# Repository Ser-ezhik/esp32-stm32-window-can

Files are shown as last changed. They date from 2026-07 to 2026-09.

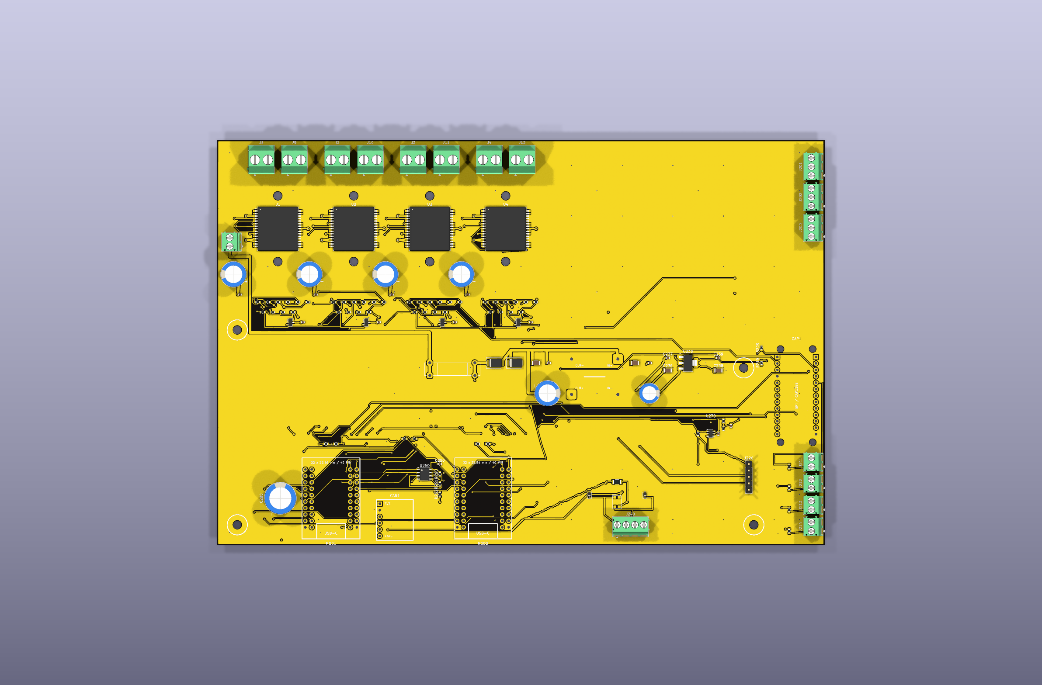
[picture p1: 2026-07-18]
hardware/WINDOW-4CH/WINDOW-4CH-top.png

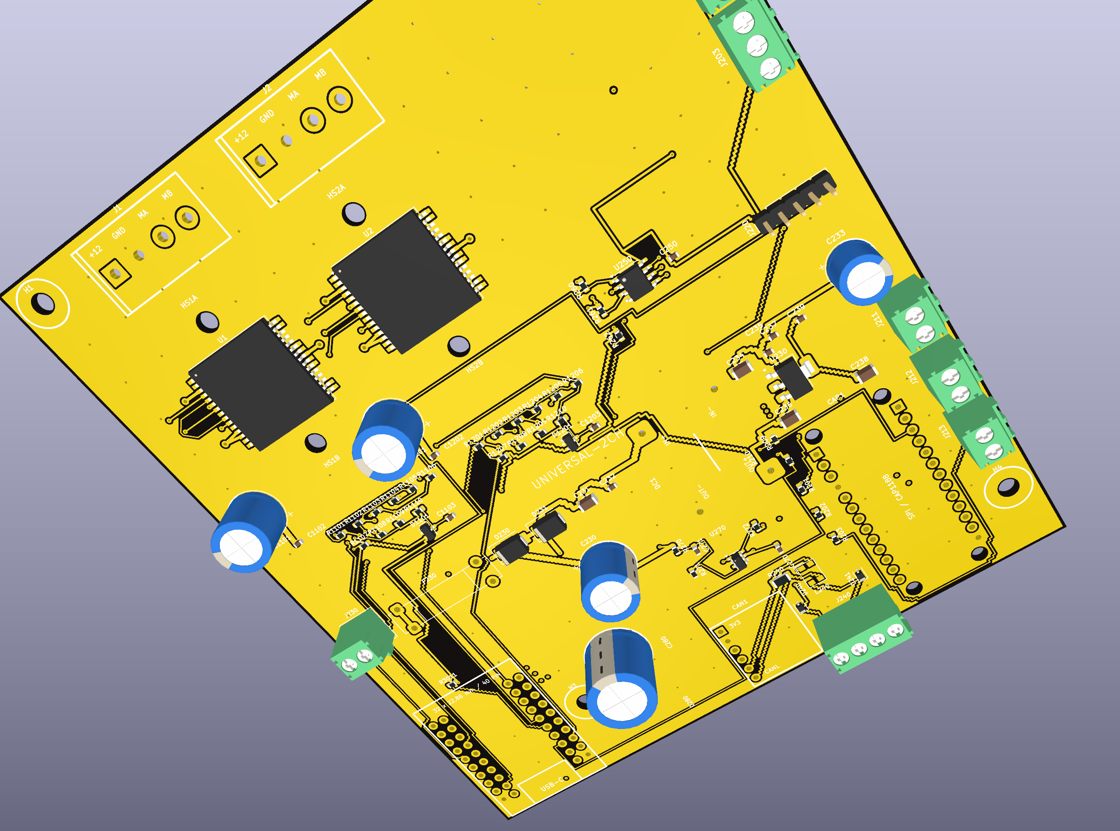
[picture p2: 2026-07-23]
hardware/UNIVERSAL-2CH/kicad/UNIVERSAL-2CH-render-iso-2400.png

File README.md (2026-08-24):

# ESP32 + STM32 window and door controller

New hardware generation of the original `esp32-rp2040-window-rs485` project.
The legacy source and all historic firmware releases remain in Git history and
under the `legacy-rp2040-import` tag. New releases never replace previous binaries.

## Target architecture

- ESP32-S3: CC1101 433 MHz radio, Wi-Fi, web UI, configuration backup and CAN coordinator.
- One cabinet per physical window or door.
- One universal STM32F103C8T6 master in each cabinet: two VNH5019A-E channels, CAN,
  CAP1188 over 4-wire SPI, three D-M9 position sensors and up to three local UART slaves.
- Up to three identical STM32 boards as local slaves, two VNH5019A-E channels per board.
- One firmware image for every STM32 board. `SLOT_ID` pins on the cabinet carrier select
  master/slave role, so a pre-flashed spare module can replace any controller.
- Cabinet identity is stored in a 25LCxx SPI EEPROM on the non-removable carrier board.

## Current development status

The current releases are STM32 two-channel `0.1.0-alpha.14`, STM32 four-channel
`0.1.0-alpha.13`, and ESP32-S3 `0.1.0-alpha.12`:

- hardware bxCAN at 500 kbit/s;
- three hardware UART links at 250 kbit/s with CRC16 frames;
- VNH5019A-E PWM, direction, current sense and diagnostic monitoring;
- CAP1188 4-wire SPI driver, no I2C;
- three active-low D-M9N inputs;
- current disappearance end-stop detection;
- overcurrent, no-current, timeout, edge and communication fail-safe states;
- per-direction full-stroke calibration data and PWM equalization;
- carrier provisioning/discovery protocol;
- watchdog and safe outputs at boot.
- bounded CAN/UART receive work per control-loop pass;
- validation of command, fault and object-type values received from the bus;
- verified internal configuration writes with retries and a latched storage fault;
- ESP32-S3 CAN coordinator with CC1101 receiver and configuration stored in NVS;
- object-based web UI for up to 64 windows/doors, actuator telemetry, events and emergency stop;
- editable 433 MHz button assignments;
- separate open/close calibration, position-aware full-cycle calibration and calibration reset;
- per-input D-M9N/D-M9P polarity stored in the cabinet carrier EEPROM.

The `alpha.1` STM32 binaries and tag remain unchanged. `alpha.2` is a new release
because the CAN protocol gained a calibration-reset command.

ESP32 `alpha.3` fixes mobile-width overflow found during Chrome testing. The
wide actuator table now scrolls inside its own container without widening the page.

ESP32 `alpha.4` targets the tested ESP32-S3 N16R8 module: 16 MB quad Flash,
PSRAM disabled (the firmware does not need it), and a 3 MB application partition. It also prints startup diagnostics
at 115200 baud. This hardware is verified with Arduino-ESP32 core `3.0.7`;
do not use core `3.3.8` for it because Wi-Fi startup is unstable on the tested board.
Generic 4 MB images remain archived under their original tags.

## Build STM32 firmware

Install Arduino CLI and the official STM32 core, then run:

```powershell
arduino-cli compile `
  --fqbn "STMicroelectronics:stm32:GenF1:pnum=GENERIC_F103C8TX,xserial=none,usb=none,opt=oslto,dbg=none,rtlib=nano" `
  --libraries libraries `
  --export-binaries `
  ArduinoIDE\STM32_Universal_Actuator_Node
```

The project deliberately targets the real 64 KiB capacity of STM32F103C8T6 and
does not rely on unofficial 128 KiB clone behaviour.

## Build ESP32-S3 firmware

```powershell
powershell -ExecutionPolicy Bypass -File tools\embed-web.ps1
arduino-cli core install esp32:esp32@3.0.7
arduino-cli compile `
  --fqbn "esp32:esp32:esp32s3:FlashMode=dio,FlashSize=16M,PartitionScheme=app3M_fat9M_16MB,PSRAM=disabled" `
  --libraries libraries `
  --export-binaries ArduinoIDE\ESP32_CC1101_CAN_Master
```

The current web interface intentionally exposes only full open, full close and
stop. A partial ventilation command will be added only after its position rule
or dedicated sensor is defined and bench-tested.

## Documentation

- `docs/HARDWARE_ARCHITECTURE.md`
- `docs/CAN_PROTOCOL.md`
- `docs/SAFETY_AND_RECOVERY.md`
- `docs/BOM_v0.1.md`
- `hardware/DOOR-8CH/README.md`
- `hardware/WINDOW-4CH/README.md`

This is safety-related motion-control software. Test with disconnected mechanics
and current-limited power before connecting a door or window.

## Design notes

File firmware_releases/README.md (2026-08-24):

# Архив версий прошивок

В этой папке сохраняются готовые версии прошивок ESP32 и RP2040.

Правило работы:

- рабочие `.ino` в `ArduinoIDE/` можно редактировать;
- готовые проверенные версии копируются сюда в отдельную папку;
- имена папок содержат дату, номер версии и краткое описание;
- старые папки релизов не затираются, чтобы можно было вернуться назад.

## Текущие версии

- `2026-08-25_v0.1.0-alpha.14-stm32-validated-io` - двухканальная STM32 с
  ограничением обработки очередей CAN/UART, проверкой входящих значений и
  проверяемой записью настроек EEPROM.
- `2026-08-25_v0.1.0-alpha.12-esp32-config-storage-fault` - ESP32-S3 с
  отображением ошибки памяти настроек STM32.

- `2026-07-08_v1.1_safety-fixes` - версия с исправлениями надежности RF, backup, watchdog, INA219, CAP1188 и I2C.
- `2026-07-08_v1.2_reed-stop` - RP2040 версия, где целевые герконы `Открыто`, `Проветривание`, `Закрыто` останавливают актуаторы.
- `2026-07-08_v1.2_reed-labels` - ESP32 версия, где герконы в веб-интерфейсе отображаются с названиями и статусом `0/1`.
- `2026-07-08_v1.3_watchdog-counter` - ESP32 и RP2040 версия со счетчиком watchdog-перезапусков RP2040.
- `2026-07-08_v1.4_web-update` - ESP32 версия с web-обновлением прошивки ESP32 через файл `.bin`.

## Как выбирать файл

- Для ESP32 через веб-обновление обычно используется `.bin`.
- Для полной прошивки ESP32 используется `.merged.bin`.
- Для RP2040 используется `.uf2`.

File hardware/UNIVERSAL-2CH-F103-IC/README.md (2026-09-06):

# UNIVERSAL-2CH-F103-IC

Compact universal two-actuator controller board with direct-mounted
STM32F103C8T6 and CAP1188 ICs.

## Board status

- two copper layers: F.Cu and B.Cu;
- board size: 83.1 x 100.1 mm;
- 106 footprints;
- 2 VNH5019A-E actuator channels;
- 2 protected 5 V reed-sensor connectors (5V/SIG/GND);
- 3 capacitive sensor connectors;
- CAN transceiver module socket;
- external fixed 5 V DC-DC footprint: 18 x 13 mm body, 15 x 9 mm pad spacing;
- SPI EEPROM and power-fail supervision;
- full GND planes on both layers;
- local copper reinforcement on all motor output and fused 12 V routes.

## Verification

KiCad 10 DRC result:

- 0 DRC errors, 0 warnings;
- 0 unconnected pads;
- 0 footprint errors.

These results were regenerated on 2026-09-06 after relocating conflicting
silkscreen text and refilling copper with a 0.8 mm minimum feature width.
Check severities were not weakened. See fabrication/v1.7-alpha15-drc-clean/RELEASE.md.

Open `kicad/UNIVERSAL-2CH-F103-IC.kicad_pro` in KiCad.

## Assembly links

The board requires three insulated wire links: `C280+ -> J280B`,
`TP290 -> JP290 (J220.6)`, and `D230.1 -> C270.1`.
See `REED_5V_PROTECTION.md` before powering the
board.

## Fabrication releases

- `fabrication/v1.7-alpha15-drc-clean` contains current Gerbers, drill files,
  stencil files, BOM and CPL. C340 is on the top side. Prior releases are stale
  for this PCB revision and must not be mixed with these manufacturing files.
- `fabrication/v1.6-reed5v-protected` is a historical release. It
  powers J201/J202 from 5 V and adds 4.7 kOhm protected signal inputs.
- `fabrication/v1.5-c88056` is retained as the preceding release. It preserves the
  verified v1.4 Gerber/CPL and replaces the unavailable L240 with TDK
  ACT45B-101-2P-TL003 (`C88056`).
- `fabrication/v1.4-orientation-verified` is retained as the preceding release.
  It includes `F.Mask` and `B.Mask`, the corrected JLCPCB BOM/CPL files, DRC
  report, Gerber ZIP, the JLCPCB placement screenshot, and a component-by-
  component orientation check. The JLCPCB cart project is `Y14`.
- `fabrication/v1.1-maskfix`, `v1.2-orientationfix`, and
  `v1.3-orientation-audit` are retained for history and must not be ordered.
- `fabrication/v1.0-audited` must not be manufactured: its Gerber archive was
  generated without the solder-mask layers.

The release build stops with an error if either copper layer, either
solder-mask layer, or the board outline is missing.

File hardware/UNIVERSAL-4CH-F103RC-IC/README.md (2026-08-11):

# UNIVERSAL-4CH-F103RC-IC

Compact four-actuator controller based on one STM32F103RCT6.

## Routed board

- Board outline: 124.05 x 93.05 mm.
- Layers: two copper layers.
- Controller: STM32F103RCT6, LQFP64, soldered on the bottom.
- Motor drivers: four VNH5019A-E, soldered on the bottom.
- Motor connectors: four keyed 4-pin connectors on the top edge.
- Reed switches: three 3-pin connectors on the bottom edge.
- Capacitive sensors: three 2-pin connectors on the right edge.
- CAP1188, SPI flash EEPROM and low-voltage SMD parts are soldered on the bottom.
- CAN transceiver and MP1584 5 V converter remain replaceable top-side modules.
- Two unplated heatsink mounting holes are provided around each VNH5019A-E.
- The 12 main motor supply/output paths are reinforced by boolean-union copper
  zones with a nominal 3.0 mm width; local connector/pad breakouts narrow only
  where adjacent plated contacts limit the available clearance.
- Every clearance-permitted underlying power segment is widened to 0.6 mm;
  only short package/connector fanouts retain their smaller library width and
  remain fully covered by the reinforced copper zones.
- CH1 OUTA has a nine-via transition bank and CH2 OUTA has six parallel vias.
  CH3/CH4 OUTA use 3 x 3 via banks at both transitions, and the CH4 OUTB
  auxiliary transition has four parallel vias. CH1-CH3 OUTB stay on B.Cu
  throughout and therefore carry no motor current through vias.
- Both copper layers include GND planes.
- Reed connectors supply 5 V and use 4.7 kohm series protection for accidental
  D-M9P connection to a 3.3 V MCU input.

## Assembly note

Fit one short insulated wire from the positive lead of `C280` to `J280B` on the
bottom side. This connects the hold-up capacitor after `D280` to the input of
the 3.3 V regulator. The connection is explicitly marked on B.Silkscreen.

## Checks

- KiCad DRC: 0 violations, 0 unconnected pads.
- Automated critical pad/net contract check: PASS.
- Automated effective-copper audit: PASS for all 12 power paths. With 2 oz
  copper, estimated planar path resistance is 1.1-2.6 milliohm and estimated
  dissipation at the 5 A design-check current is at most 0.10 W per path
  (excluding the small additional resistance of plated transitions).
- Four VNH channels, CAP1188 SPI, EEPROM SPI, remapped CAN, SWD, power-good and
  three protected reed inputs are included in the contract check.
- Channel 3 and 4 ADC clamps and diagnostic pull-ups are connected to the
  powered `S1_3V3` rail; the electrical audit rejects the former orphan rail.

Use 2 oz finished copper for production. The expected actuator current is
about 2.5 A; 5 A is the routing verification current, not the continuous-load
rating of the complete controller assembly.

## Firmware

Use `ArduinoIDE/STM32_Universal_Actuator_Node_4CH_F103RC`. It publishes two
classic-CAN actuator frames, each containing two local channels, and is
compatible with the existing ESP32 four-actuator object model. Build it with
`tools/build-stm32-4ch-f103rc.ps1`. The existing F103C8 two-channel binary must
not be flashed onto this board.

Open `kicad/UNIVERSAL-4CH-F103RC-IC.kicad_pcb` in KiCad 10.

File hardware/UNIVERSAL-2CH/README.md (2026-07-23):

# UNIVERSAL-2CH

Compact universal carrier for two 12 V linear actuators. The same assembled
board can be provisioned as an optional sliding-door drive or as a two-actuator
vent/window node.

## Hardware

- Board: 106 x 112 mm, four copper layers.
- Controller: one socketed STM32F103C8T6 Mini.
- Drivers: two VNH5019A-E channels with mounting holes for top heatsinks.
- Network: socketed SN65HVD230 CAN transceiver module and protected edge entry.
- Touch safety: optional socketed CAP1188 SPI module with three field inputs.
- Position: three protected reed-switch inputs.
- Identity and journal: 25LC256 carrier EEPROM.
- Supply: socketed MP1584 12 V to 5 V converter, 3.3 V regulator, power-good
  monitor, and logic hold-up capacitor.

## Connectors

- `J1`, `J2`: actuator connectors, `+12V / GND / MA / MB`.
- `J201` to `J203`: open, closed, and in-place reed sensors.
- `J211` to `J213`: capacitive field sensors.
- `J230`: protected 12 V logic input.
- `J240`: `CANH / CANL / GND / shield`.
- `J220`: SWD service header.

All external field connectors are placed on board edges. Power routing and
VNH5019 devices occupy the upper half; CAN and touch electronics are kept away
from the motor outputs.

The field interfaces use board-mounted male headers with removable female cable
plugs. Connector fronts face outwards; the layout includes body clearance
between adjacent plugs and keeps the cable-entry space outside the board edge.

## KiCad Files

- `kicad/UNIVERSAL-2CH.kicad_pcb`: routed PCB.
- `kicad/UNIVERSAL-2CH.kicad_sch`: complete flat schematic.
- `kicad/UNIVERSAL-2CH-multisheet.kicad_sch`: multisheet root schematic.
- `kicad/UNIVERSAL-2CH-routed-top.png`: final top-side 3D render.
- `kicad/UNIVERSAL-2CH-routed-iso.png`: final isometric 3D render.
- `UNIVERSAL-2CH-BOM.csv`: grouped BOM.

## Verification

- PCB DRC: 0 violations, 0 unconnected items.
- Flat schematic ERC: 0 errors, 0 warnings.
- Multisheet schematic ERC: 0 errors, 0 warnings.
- PCB-to-schematic sync: 90 references, 283 connected pads, 38 explicit NCs.
- Routing geometry: straight segments with 45-degree transitions; no staircase
  routing on long connections.
- STM32 pin audit: 27 functional socket connections match `config.h`.
- STM32 build: 24,136 bytes Flash (36%), 3,500 bytes RAM (17%).

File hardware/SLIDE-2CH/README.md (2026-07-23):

# SLIDE-2CH optional automatic-door module

## Purpose

`SLIDE-2CH` is an optional compact CAN node for two 12 V actuators that slide
door leaves after the main door mechanism has opened. It uses the same socketed
STM32 module, VNH5019A-E circuit and universal firmware as the existing boards.
No different STM32 binary is required.

The module is configured as:

- object type `Window`;
- actuator count `2`;
- slave count `0`;
- CAP1188 enabled mask `0`;
- its own unique CAN cabinet number.

ESP32 links this node to a single- or double-door object. When the option is
disabled or the module is absent, the existing door operates unchanged.

## Required hardware

- one socketed STM32F103C8T6 mini module;
- two VNH5019A-E bridges with the complete DOOR-8CH passive and current-sense
  networks;
- one SN65HVD230 CAN transceiver module;
- one 25LC256 carrier EEPROM;
- one MP1584 12 V to 5 V module and the existing protected logic-power input;
- two keyed four-pin actuator connectors carrying 12 V, GND, OUTA and OUTB;
- one CAN connector with TVS, common-mode choke and optional DNP 120 Ohm
  termination;
- three D-M9 reed inputs: fully open, fully closed and mechanism in-place;
- per-channel 7.5 A fuses and local 470 uF / 35 V capacitors;
- SWD connector, power-good circuit and MASTER hold-up supply.

The open and closed reeds are mandatory for deterministic operation after a
cold start. The actuator internal limit switches remain the normal end-of-travel
and calibration signal, but they cannot report the initial position while the
motor is unpowered.

## Safe sequence

Opening:

1. ESP32 verifies that both CAN nodes are online and fault-free.
2. The main door mechanism opens completely.
3. After the configured delay, SLIDE-2CH opens both sliding actuators.

Closing:

1. SLIDE-2CH closes both sliding actuators.
2. After the configured delay, the main door mechanism closes.

During either sequence, a fault, movement timeout or loss of fresh telemetry
stops both nodes. A CAP1188 touch on the main door during closing is sent
immediately over CAN and also stops both nodes. Each moving STM32 independently
stops within 300 ms if ESP32 heartbeats disappear.

## PCB derivation

The electrical implementation must be copied from the S1 section and channels
1/2 of `hardware/DOOR-8CH`, not from the archived `ACT-CARRIER-2CH` study.
Keep both VNH zones and actuator connectors on one board edge, and keep CAN,
STM32, EEPROM, reeds and sensor routing on the opposite quiet edge. The VNH
heatsink holes and keepouts remain identical to DOOR-8CH.

This document defines the approved architecture. A routed KiCad PCB and
fabrication package are a separate hardware release and must pass ERC/DRC and
the same schematic-to-firmware pin audit as DOOR-8CH.

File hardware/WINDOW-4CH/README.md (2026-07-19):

# WINDOW-4CH carrier

`WINDOW-4CH` is the separate four-actuator carrier for one window. It does not
replace or modify `DOOR-8CH`.

## Architecture

- S1 is the MASTER STM32F103C8T6 and controls actuator channels 1 and 2.
- S2 is the SLAVE STM32F103C8T6 and controls channels 3 and 4.
- S1 and S2 use a direct 250 kbit/s UART link inside the cabinet.
- Only S1 is connected to the 500 kbit/s CAN bus through one SN65HVD230 module.
- One CAP1188 module provides four field connectors: three working edge
  sensors and one spare channel.
- Three D-M9 reed inputs report open, closed and in-place positions.
- One 25LC256 carrier EEPROM stores cabinet identity and the power-loss record.
- U270, D280 and C280 provide power-fail detection and MASTER hold-up.

The compact board outline is 155 x 150 mm and uses four copper layers. All external
power, actuator, CAN, reed and capacitive-sensor connectors are placed at board
edges. The SWD service connector remains inside the low-voltage service area.
Four VNH5019A-E channels retain the same protection, current sensing, bulk
capacitance and top-mounted heatsink hole pattern as the validated 8-channel
design. Clearance-checked GND stitching vias tie all four copper layers together
around the power section.

## KiCad files

- `kicad/WINDOW-4CH.kicad_pcb` - routed KiCad 10 PCB.
- `kicad/WINDOW-4CH.kicad_sch` - complete flat schematic.
- `kicad/WINDOW-4CH-multisheet.kicad_sch` - recommended multisheet entry.
- `WINDOW-4CH-BOM.csv` - grouped bill of materials.
- `SCHEMATIC_FIRMWARE_AUDIT.md` - firmware pin and configuration audit.

The PCB passes DRC with zero violations and zero unconnected items. The flat
and multisheet schematics pass ERC with zero errors. Isolated-label warnings
are retained for universal STM32 pins that are deliberately unused on this
two-controller carrier.

## Required cabinet configuration

Provision S1 as an object with:

- object type: window (`0`);
- actuator count in the ESP32 object table: `4`;
- slave count in the carrier EEPROM: `1`;
- CAP enabled mask: normally `0x07`; use bit 3 only when the spare sensor is
  populated;
- reed polarity mask bits 0..2 according to the installed D-M9N/D-M9P sensors.

S2 is identified by the carrier slot straps and uses the same universal STM32
firmware as S1. A replacement STM32 module therefore requires no location-
specific firmware.

## Before fabrication

1. Check the photographed STM32, CAP1188, CAN and MP1584 modules on a 1:1 print.
2. Assemble and test one VNH5019 channel before ordering the full quantity.
3. Calibrate current conversion and overcurrent limits on the real actuator.
4. Measure C280 hold-up time at low temperature and confirm a complete EEPROM
   power-loss write after repeated 12 V removal.
5. Do not release production Gerbers until those physical checks are complete.

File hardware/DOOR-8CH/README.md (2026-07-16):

# DOOR-8CH v0.1

## Status

This is the active PCB architecture for the project. One DOOR-8CH board is
installed in each cabinet. It is universal: the same board serves a window, a
four-actuator single door or an eight-actuator double door by populating one,
two or four identical two-channel slots.

The earlier `ACT-CARRIER-2CH` concept remains in the repository as a superseded
study only. Do not fabricate it.

## Slot population

| Cabinet | Fitted slots | STM32 | VNH5019A-E |
| --- | ---: | ---: | ---: |
| Window | S1 | 1 | 2 |
| Single door | S1, S2 | 2 | 4 |
| Double door | S1, S2, S3, S4 | 4 | 8 |

Every slot has one socketed STM32 mini board and two VNH5019A-E channels. S1 is
always MASTER. S2 through S4 are SLAVEs when populated. This preserves the
repair rule: any programmed STM32 mini board can replace any other STM32 mini
board after inserting it in the same slot.

The carrier identifies the slot with two board straps sampled on PB2 and PA7
before peripheral initialisation. See
[`kicad/STM32_MODULE_PINMAP.md`](kicad/STM32_MODULE_PINMAP.md). This replaces
the earlier PC14/PC15 proposal, because both pins are not available on the
photographed module.

## Internal UART routing

No UART cable leaves the board. The following tracks are routed directly on the
DOOR-8CH PCB, with a shared signal-ground plane:

| Master UART | MASTER STM32 pins | SLAVE STM32 pins | Destination slot |
| --- | --- | --- | --- |
| UART 1 | PB6 TX, PB7 RX | PB7 RX, PB6 TX | S2 |
| UART 2 | PA2 TX, PA3 RX | PB7 RX, PB6 TX | S3 |
| UART 3 | PB10 TX, PB11 RX | PB7 RX, PB6 TX | S4 |

Place 100 Ohm series resistors at each transmitter, as specified in the BOM.
These links are short PCB traces within one cabinet and operate at 250 kbit/s.

## On-board modules

All selected off-the-shelf modules plug directly into headers on the DOOR-8CH
board. There are no loose SPI, CAN or UART jumpers between them.

| Zone / module | Fitted on | Board connection |
| --- | --- | --- |
| MASTER CAN: SN65HVD230 | Every board, S1 zone | PA12 CTX, PA11 CRX, CANH/CANL trunk |
| ESP32-S3 board | Double-door board only | 5 V, GND, its CAN and CC1101 signals |
| ESP CAN: SN65HVD230 | Double-door board only | GPIO39 CTX, GPIO38 CRX, same CAN trunk |
| CC1101 433 MHz | Double-door board only | GPIO10-13, GPIO4, GPIO5, 3.3 V |
| CAP1188 SPI breakout | Every board, including the window | PA4-PA7, PB9, PB13, 5 V VIN; eight C/GND field connectors |
| 25LC256 carrier EEPROM | Every board, S1 zone | PA15 CS plus shared SPI pins PA5, PA6, PA7 |
| Reeds A | Every board, S1 zone | S1 PB0, PB1, PB8 |
| Reeds B | Double-door build only | S2 PB0, PB1, PB8, reported to S1 over UART |
| Power-good comparator | Every board, S1 zone | PC13 |

CAN enters at the quiet lower service edge next to the optional ESP CAN module
`CAN2`. The connector is followed by TVS protection, a common-mode choke and
optional 120 Ohm termination, then branches to both `CAN1` and `CAN2`. S2-S4
have no CAN transceivers or external CAN connectors.

## Power architecture

The selected MP1584 module plugs or solders directly into the DOOR-8CH board and
produces one protected `LOGIC_5V` feed for the whole board. Its dedicated edge
input, 1 A branch fuse, reverse-polarity diode, SMBJ16A and input/output filters
are all on the same PCB; no loose DC/DC wiring is used.
The board generates one `LOGIC_3V3` rail from `LOGIC_5V` with a local AMS1117
style regulator for CAN, CC1101 and other plug-in module supplies. STM32 mini
board 3.3 V pins remain local to their own slot and are not tied together.
Each STM32 mini board receives 5 V from the protected logic rail.

S1 is supplied through D280 (`SS34`) from `LOGIC_5V`; C280 (4700 uF / 10 V,
low ESR) holds its isolated `S1_5V_HOLD` rail during a power failure. U270
monitors the fused 12 V input and pulls S1 PC13 low near 9.3 V. The EEPROM and
its pull-ups use the resulting held `S1_3V3` rail, allowing the MASTER to stop
outputs and finish one outage-record write before brownout.

The external SPI EEPROM stores the cabinet identity, object type, slave count
and reed polarity mask. See [CARRIER_EEPROM_MAP.md](CARRIER_EEPROM_MAP.md).
This keeps the STM32 firmware universal: a replacement STM32 module reads the
same carrier data after installation.

Motor power is intentionally not bussed across the PCB:

- each VNH channel receives its own `FUSED_12V_CHx` and GND pair from the
  cabinet fuse distribution;
- every channel remains protected by its own 7.5 A fuse;
- there is no 40 A trace from the double-door supply input to the VNH slots;
- local 470 uF / 35 V capacitors remain beside every VNH5019.

This keeps the double-door's eight-channel current out of a single board-wide
power bottleneck while eliminating inter-board UART and logic-power wiring.

## Mandatory VNH passives and heatsink provision

Every VNH5019 receives its complete passive network: reset-safe input pull-downs,
series resistors, diagnostic pull-up, CS_DIS pull-down, calibrated current-sense
resistors, ADC filter and local 470 uF / 35 V plus 100 nF power decoupling.
Each VNH zone also has a 30 x 30 mm heatsink keepout and two M3 holes for a
small external heatsink. See [VNH_THERMAL_AND_PASSIVES.md](VNH_THERMAL_AND_PASSIVES.md).

## Preliminary mechanical plan

- One board, maximum initial outline: 260 x 160 mm.
- Four VNH zones along the long actuator-connector edge; each zone has two
  actuator terminal blocks and two separately fused power-input pairs.
- Four STM32 sockets form the low-voltage centre strip.
- CAN, CAP1188, reeds, SWD, ESP32-S3, CC1101 and both CAN-module sockets sit at
  the lower/right service edges, away from the top motor-current terminals.
- S3 / `MOD3` is shifted right to keep the CAN trunk connector and protection
  physically close to `CAN2`.
- Eight separate 2-pin `CSx/GND` connectors for CAP1188 twisted pairs sit at a
  board edge. Firmware selects any active subset; unused channels remain disabled.
- Six three-pin reed connectors sit at the same field-connector edge: 3V3,
  signal and GND. A double door uses three on S1 for leaf A and three on S2 for
  leaf B.
- Four layers, 2 oz external copper. VNH exposed pads receive thermal via arrays
  to internal copper areas.

The final outline is set after the selected 5.08 mm terminals are checked on a
1:1 print. This is a PCB design input, not a Gerber release.

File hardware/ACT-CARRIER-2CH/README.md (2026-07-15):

# ACT-CARRIER-2CH v0.1 - superseded

## Status

This is an archived electrical and layout study. It is **superseded by
`hardware/DOOR-8CH` and must not be fabricated**. One board accepts one removable
STM32F103C8T6 mini module and controls two 12 V linear actuators through two
bare VNH5019A-E H-bridges. The board is repeated: one per two actuators.

The same PCB was intended for every slot. MASTER-only functions use unpopulated
headers or DNP parts on SLAVE boards. Board role is selected by two straps on
the carrier; firmware never depends on which physical STM32 board is inserted.

The current visual placement study is
[PRELIMINARY_PLACEMENT.svg](PRELIMINARY_PLACEMENT.svg). It is a component
placement guide, not a routed PCB or fabrication file.

For the physical arrangement of four of these boards in the double-door cabinet,
see [DOUBLE_DOOR_CABINET.svg](DOUBLE_DOOR_CABINET.svg).

## Board boundary

The PCB contains:

- socket footprint for the STM32F103C8T6 mini board;
- two VNH5019A-E channels and their current-sense circuits;
- motor connectors, 12 V motor input and 5 V logic input;
- 3.3 V auxiliary LDO for CAN, EEPROM, CAP1188 and VNH diagnostic pull-ups;
- slot straps, local UART headers and optional MASTER headers;
- test pads for 12 V, 5 V, 3.3 V, both CS signals and both diagnostic signals.

The cabinet, not this carrier, contains the MP1584 12 V to 5 V module, the
logic-branch fuse, reverse-polarity protection, SMBJ16A and cabinet-level
power-entry capacitors. Per-actuator 7.5 A fuses are also external so they can
be inspected and replaced without removing a PCB.

## Electrical design

### Power nets

| Net | Source | Use |
| --- | --- | --- |
| `MOTOR_12V_CH1` | Cabinet fuse F1 output | U1 `VBAT` and `VCC` pins only. |
| `MOTOR_12V_CH2` | Cabinet fuse F2 output | U2 `VBAT` and `VCC` pins only. |
| `MOTOR_GND` | Cabinet star ground | VNH `GNDA` and `GNDB`, motor-current return. |
| `LOGIC_5V` | Cabinet MP1584 output | STM32 mini board `5V`, carrier 3.3 V LDO input. |
| `LOGIC_3V3` | Carrier 5 V to 3.3 V LDO | CAN/CAP/EEPROM, DIAG pull-ups, sensor headers. |
| `SIGNAL_GND` | Joined to `MOTOR_GND` at board power entry | Logic and measurement reference. |

The 3.3 V auxiliary LDO deliberately powers external peripherals instead of
loading the small regulator on an unknown STM32 mini board. The STM32 board is
fed through its `5V` pin and generates 3.3 V only for itself.

### One VNH5019A-E channel

`U1` and `U2` use the ST MultiPowerSO-30 footprint and the exact pin mapping
from the VNH5019A-E data sheet:

| VNH pins | Connection |
| --- | --- |
| `3, 13, 23, slug 1 (VCC)` and `12 (VBAT)` | That channel's `MOTOR_12V_CHx`; VBAT and VCC are shorted because reverse-polarity protection is at the cabinet entry. |
| `26, 27, 28 (GNDA)` and `18, 19, 20 (GNDB)` | `MOTOR_GND`, joined immediately under the package. |
| `1, 25, 30, slug 2 (OUTA)` | Actuator terminal A. |
| `15, 16, 21, slug 3 (OUTB)` | Actuator terminal B. |
| `4 INA`, `10 INB`, `7 PWM` | STM32 output through 100 Ohm; every signal has a 10 kOhm pull-down at the VNH side. |
| `5 ENA/DIAGA`, `9 ENB/DIAGB` | Tied together, pulled to `LOGIC_3V3` by 4.7 kOhm and routed to the corresponding STM32 diagnostic input. |
| `6 CS_DIS` | 10 kOhm pull-down to `SIGNAL_GND`; current sensing stays enabled. |
| `8 CS` | Current-sense chain below. |
| `11 CP` | DNP test pad. It is not used because reverse-polarity protection is external to the carrier. |

For each bridge, fit `470 uF / 35 V low-ESR` plus `100 nF / 50 V X7R` directly
between its `MOTOR_12V_CHx` net and `MOTOR_GND`. The 470 uF value follows ST's basic
orientation of 500 uF per 10 A motor load; it is local energy storage and must
not be moved to the cabinet end of a long wire.

### Current sense

Each channel is implemented identically:

```text
VNH CS --+-- 1.00k 1% -- SIGNAL_GND
          |
          +-- 68k 1% -- SENSE_DIV -- 100k 1% -- SIGNAL_GND
                                |
                             1k series
                                |
                          PA0 or PA1
                                |
                            100nF to GND
```

`PA0` measures actuator 1 and `PA1` measures actuator 2. The known nominal
conversion is about 84.6 mV/A at the ADC. It is calibrated from a real current
measurement on the first assembled board before the 5 A software limit is used.

### STM32 signal assignment

| Channel / function | STM32 pin |
| --- | --- |
| Actuator 1: CS / PWM / INA / INB / DIAG | PA0 / PA8 / PB14 / PB15 / PB5 |
| Actuator 2: CS / PWM / INA / INB / DIAG | PA1 / PA9 / PB3 / PB4 / PB12 |
| Slot straps | PC14, PC15 |
| Slave upstream UART | PB7 RX, PB6 TX |
| Master UART links 1 / 2 / 3 | PB7/PB6, PA2/PA3, PB11/PB10 |
| CAN module header | PA11 RX, PA12 TX |
| CAP1188 header | PA4, PA5, PA6, PA7, PB9, PB13 |
| Reed header | PB0, PB1, PB8 |
| EEPROM chip select | PA15 |
| 12 V power-good input | PC13 |

PB3 and PB4 require JTAG disabled while retaining SWD, as the firmware already
does. The selected mini-board is documented in
[STM32_MINI_BOARD_VARIANT.md](STM32_MINI_BOARD_VARIANT.md). It must use its
CH340 UART configuration, not its native USB configuration: PA11/PA12 are
reserved for CAN. PC14/PC15 can be occupied by an LSE crystal on some variants.

## Connectors and optional population

| Ref | Part / function | Fit on |
| --- | --- | --- |
| J1 | `MOTOR_12V_CH1`, GND, `MOTOR_12V_CH2`, GND; 4-pin locking power input | Every carrier. Each 12 V pin comes after its own 7.5 A fuse. |
| J2, J3 | 2-pin, 5.08 mm-pitch actuator output, >=10 A per contact | Every carrier; selected terminal is documented in [TERMINAL_BLOCK_SELECTION.md](TERMINAL_BLOCK_SELECTION.md). |
| J4 | `LOGIC_5V`, `SIGNAL_GND`, 2-pin locking input | Every carrier |
| J5 | SWD: 3.3 V, SWDIO, SWCLK, GND, NRST | Every carrier |
| J6 | Upstream UART: TX, RX, GND, 3.3 V reference | Every carrier |
| J7/J8/J9 | Downstream UART 1/2/3 | MASTER only |
| J10 | SN65HVD230 module: 3V3, GND, CTX, CRX, CANH, CANL | MASTER only |
| J11 | CAP1188: 3V3, GND, CS, SCK, MISO, MOSI, RST, IRQ | MASTER only |
| J12 | Reeds: 3.3 V, GND, REED1, REED2, REED3 | MASTER only |
| U3 | 25LC256 EEPROM and its pull-ups | MASTER only |
| U4 | 12 V power-good comparator | MASTER only |

## PCB stack-up and placement rules

1. Four layers; 2 oz outer copper, 1 oz inner copper; FR-4 1.6 mm.
2. Layer 2 is an uninterrupted `MOTOR_GND` plane except for a controlled logic
   island near the STM32 socket. Layer 3 carries `MOTOR_12V` and low-current
   routing.
3. Put U1/U2 at the actuator-connector edge. Each exposed slug has a large
   copper island with dense thermal via arrays to layers 2 and 3.
4. Keep the motor-current loop: VNH VCC - bridge - OUTA/OUTB - actuator cable -
   return - VNH GND as short and wide as possible. No signal trace may cross it.
5. Place the 470 uF capacitor and 100 nF capacitor beside their VNH power pins,
   not beside J1.
6. Keep CS divider, PA0/PA1 and their 100 nF capacitors beside the STM32 socket
   and away from OUTA/OUTB and PWM routes.
7. Use no thermal relief on VNH power pads or motor connector pads. Use at least
   4 mm copper width for a 5 A outer-layer path, wider wherever space permits.
8. Maintain at least 3 mm clearance between motor copper and low-voltage logic
   copper; use a grounded copper guard where it improves noise immunity.
9. No copper pours under the CAP1188 connector or its electrode-cable exit.

## Fabrication gate

Before generating Gerbers, complete all four checks:

1. Verify one physical STM32 mini board against the documented 2x15 footprint,
   including continuity of PA9/PA10, PC14 and PC15 to its USB/LSE circuitry.
2. Implement the ST MultiPowerSO-30 recommended land pattern exactly, verify it
   in KiCad against the data sheet, then inspect solder wetting and thermal-pad
   voiding on the first assembled prototype.
3. Obtain the selected 5.08 mm actuator-output terminal and confirm pin diameter
   and body outline against the carrier footprint.
4. Review the resulting KiCad schematic with ERC, then check the 3D/1:1 print
   of connector and module placement before ordering boards.

The authoritative source for VNH5019 pin use, current-sense behavior, input
thresholds and thermal layout is the [ST VNH5019A-E data sheet](https://www.st.com/resource/en/datasheet/vnh5019a-e.pdf).

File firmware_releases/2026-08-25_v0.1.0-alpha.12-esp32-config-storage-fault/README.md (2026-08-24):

# ESP32 CAN Master v0.1.0-alpha.12

Target: ESP32-S3 N16R8, Arduino-ESP32 core 3.0.7, PSRAM disabled.

This release recognizes STM32 fault code 14 (`ConfigStorage`) and displays it
as `ошибка памяти настроек`. Unknown fault values are shown as an unknown error
instead of being reported as no fault.

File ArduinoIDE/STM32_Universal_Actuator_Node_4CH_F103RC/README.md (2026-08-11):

# STM32 universal actuator node, integrated 4-channel F103RC target

Dedicated firmware for `UNIVERSAL-4CH-F103RC-IC` with one soldered
STM32F103RCT6 and four local VNH5019A-E channels.

- CAN: 500 kbit/s on remapped PB8/PB9.
- PWM: PA8/PA9/PA10/PA11, TIM1 channels 1 through 4, 20 kHz.
- Current ADC: PA0/PA1/PA2/PA3, initial scale 5.7 mA/count.
- CAP1188 and 25LC256: shared SPI1 with PA4 and PC4 chip selects.
- Sensors: three protected reed inputs and three CAP1188 electrodes.
- Power-fail input: PC3; identity and power-loss record: external 25LC256.

The classic CAN protocol still represents actuators in groups of two. This
node therefore publishes channels 1-2 in actuator slot 0 and channels 3-4 in
slot 1. ESP32 provisioning must specify four actuators (`slaveCount = 1`), but
there is no physical UART slave on this board.

The target accepts `Window` and `SingleDoor`. It rejects `DoubleDoor` because
the PCB has only one set of three reed-switch inputs.

Build from the repository root:

```powershell
.\tools\build-stm32-4ch-f103rc.ps1
```

Do not flash the two-channel F103C8 binary onto this board.

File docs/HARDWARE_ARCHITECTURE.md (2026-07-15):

# Hardware architecture

## Cabinet topology

Each physical object is one CAN node regardless of actuator count.

```text
CAN_H / CAN_L / GND
        |
        +-- one universal DOOR-8CH PCB in each cabinet
              |-- slot 1: STM32 MASTER -- 2 x VNH5019A-E -- CAN
              |-- slot 2: STM32 SLAVE1 -- 2 x VNH5019A-E -- internal UART 1
              |-- slot 3: STM32 SLAVE2 -- 2 x VNH5019A-E -- internal UART 2
              `-- slot 4: STM32 SLAVE3 -- 2 x VNH5019A-E -- internal UART 3
```

A window populates slot 1 only. A four-actuator door populates slots 1 and 2.
An eight-actuator double door populates all four slots. The UART connections are
short internal PCB tracks, so no inter-board UART cable exists.

## ESP32 controller board

The selected board is the two-USB-C `ESP32-S3-WROOM-1` development board shown
in the project photo. It is compatible with the ESP32 firmware in this repository.
Use its USB-UART port for initial flashing and serial diagnostics; the second
USB-C connector is not required by the control system.

| Function | ESP32-S3 GPIO | Connection |
| --- | ---: | --- |
| CAN RX | 38 | ESP-zone SN65HVD230 `CRX` |
| CAN TX | 39 | ESP-zone SN65HVD230 `CTX`, through 47 Ohm |
| CC1101 SCK / MISO / MOSI / CS | 12 / 13 / 11 / 10 | CC1101 SPI bus |
| CC1101 GDO0 / GDO2 | 4 / 5 | CC1101 digital outputs |
| Learn button | 9 | Button to GND, use internal pull-up |

Supply the board with regulated **5 V** from the cabinet DC/DC converter through
its `5V` pin and connect a common GND. Never feed the 12 V actuator supply into
the ESP32 board. The onboard RGB LED on GPIO47/48 is not used by the controller
firmware and remains free.

### CC1101 433 MHz module

The selected 28 x 15 mm `433M V2.0` CC1101 module has an eight-pin, two-column
header. Connect it exactly as follows; its VCC and all I/O are **3.3 V only**.

| CC1101 pin | Label | ESP32-S3 connection |
| ---: | --- | --- |
| 1 | VCC | 3.3V |
| 2 | GND | GND |
| 3 | GDO0 | GPIO4 |
| 4 | CSN | GPIO10 |
| 5 | SCK | GPIO12 |
| 6 | MOSI | GPIO11 |
| 7 | MISO / GDO1 | GPIO13; GDO1 is unused |
| 8 | GDO2 | GPIO5 |

Fit the 100 nF and 10 uF bypass capacitors listed in the BOM directly beside
this connector. Mount the supplied 433 MHz spring antenna vertically, keep it
away from the CAN cable and motor wiring, and do not place it against a metal
wall of the cabinet.

### CAN module

The pictured six-pin `3V3 / GND / CTX / CRX / CANH / CANL` module is the common
`SN65HVD230` 3.3 V CAN-transceiver board. It is electrically compatible with
the 500 kbit/s project CAN bus and plugs into the DOOR-8CH board. It is a
transceiver, not a CAN controller; the ESP32-S3 and STM32F103 provide the CAN
controller themselves.

| Module pin | STM32 MASTER | ESP32 controller |
| --- | --- | --- |
| 3V3 | 3.3V | 3.3V |
| GND | GND | GND |
| CTX | PA12 (CAN TX) | GPIO39 (CAN TX) |
| CRX | PA11 (CAN RX) | GPIO38 (CAN RX) |
| CANH | CANH trunk | CANH trunk |
| CANL | CANL trunk | CANL trunk |

Before fitting all six modules, use an unpowered multimeter to measure each
one between `CANH` and `CANL`. If it reads about 120 Ohm, it has a fitted
termination resistor and may be installed only at a physical end of the CAN
cable, or its resistor must be removed. Across the complete unpowered CAN
trunk, with exactly two 120 Ohm terminators installed, the reading must be
about **60 Ohm**. Intermediate cabinets have no termination.

This small module has no connector-level surge protection. Keep the BOM's CAN
TVS, common-mode choke and CAN_GND reference conductor at every cabinet entry.

### CAP1188 touch module

The selected `CAP1188 8-Key CapTouch SPI/I2C w/LEDs` breakout is suitable. Use
its **SPI** interface only; do not enable or connect I2C. Power its `VIN` pin
from 3.3 V, connect `GND`, and leave its `3Vo` output unconnected. The eight
LEDs are indication outputs and do not replace the capacitive inputs `C1...C8`.

| CAP1188 label | STM32 MASTER pin | Notes |
| --- | --- | --- |
| VIN | 3.3V | Do not feed 5 V in this system. |
| GND | GND | Common signal ground. |
| CS | PA4 | SPI chip select. |
| SCK | PA5 | SPI clock. |
| MISO | PA6 | SPI data from CAP1188. |
| MOSI | PA7 | SPI data to CAP1188. |
| RST | PB9 | Active-high reset, pulled down to GND with 10 kOhm. |
| IRQ | PB13 | Interrupt, pulled up to 3.3 V. |
| C1...C8 | Touch perimeter electrodes | Every reported touch is treated as a safety-edge event while closing. |

Keep the breakout and the cable to its touch electrodes away from 12 V motor
wiring and PWM tracks. For a long perimeter, use one conductor per electrode
with a nearby GND reference or screened cable; final sensitivity is adjusted
during commissioning with the actual door and cable installed. Connect every
enabled channel to a real electrode. Route all eight inputs to separate two-pin
edge connectors labelled `CS1/GND` through `CS8/GND`, so one twisted pair serves
each electrode without splices. The GND conductor is a reference/shield beside
the isolated electrode and is never shorted to the sensor conductor.

The enabled-channel mask is stored per cabinet and is configurable from the web
interface. Default profiles enable three channels for a window or single door
and six channels for a double door, but any subset of CS1...CS8 can be selected.
Disabled channels are removed from the CAP1188 Sensor Input Enable and Interrupt
Enable registers and cannot trigger a safety stop. Saving a new mask forces a
recalibration of the enabled channels with the installed cable and electrodes.

## Replaceable module identity

signals select the role at boot:
Every STM32 module carries the same firmware and interface circuit. Two DOOR-8CH
slot signals select the role at boot:
signals select the role at boot:

| SLOT_ID1 | SLOT_ID0 | Role |
| --- | --- | --- |
| 1 | 1 | MASTER |
| 1 | 0 | SLAVE1 |
| 0 | 1 | SLAVE2 |
| 0 | 0 | SLAVE3 |

The firmware reads active-low straps, therefore an empty/unstrapped test module
starts as MASTER. The cabinet address is not stored only on the replaceable MCU.
A 25LCxx-compatible SPI EEPROM on the carrier stores cabinet ID, object type and
slave count. Until that record has a valid CRC, all bridge outputs remain disabled.

## STM32F103C8T6 pin assignment

The selected MCU module is the compact USB-C `STM32F103C8T6 mini` board shown
in the project photo. It must be ordered in its **CH340 UART mode** (CH340 and
the board's R4/R5 UART links fitted), not native USB mode: PA11/PA12 are then
free for CAN. Every carrier accepts the same module; MASTER or SLAVE identity
comes only from the carrier straps and its configuration EEPROM, not from a
different STM32 firmware.

| Function | Pins |
| --- | --- |
| VNH current sense | PA0, PA1 |
| Master UART 2 | PA2 RX, PA3 TX |
| CAP1188 SPI1 | PA4 CS, PA5 SCK, PA6 MISO, PA7 MOSI |
| VNH PWM | PA8, PA9 |
| CAN | PA11 RX, PA12 TX |
| SWD | PA13, PA14 |
| Carrier EEPROM CS | PA15 |
| Reeds | PB0, PB1, PB8 |
| VNH direction | PB3, PB4, PB14, PB15 |
| VNH diagnostics | PB5, PB12 |
| Master UART 1 / slave upstream | PB7 RX, PB6 TX |
| CAP1188 reset / IRQ | PB9, PB13 |
| Master UART 3 | PB11 RX, PB10 TX |
| 12 V power-good input | PC13 |
| SLOT_ID | PC14, PC15 |

Feed the module with regulated 5 V through its `5V` pin and GND from the
cabinet low-voltage supply. Its `3V3` pin is the logic rail for its local
signals; never apply 5 V to any STM32 GPIO. The USB-C connection is for service
flashing and diagnostics. Do not connect USB power and an external 5 V cabinet
supply at the same time until the carrier's service-power isolation diode is
implemented.

JTAG must be disabled while SWD remains enabled to release PB3 and PB4. Native
USB is not used because PA11/PA12 are assigned to CAN. The board CH340 connection
on PA9/PA10 is not used as the control UART; its high-impedance RX input does
not prevent PA9 from supplying the second PWM signal.

PC14 and PC15 can only be used for `SLOT_ID` if the mini-board does not populate
the 32.768 kHz LSE crystal on those pins. Verify the actual board before making
the carrier PCB; otherwise move the two slot straps to free GPIO pins.

## Power and signal rules

- 12 V motor power and logic DC/DC branches are fused separately.
- Every actuator channel has its own fuse.
- Motor returns and logic ground meet at the cabinet power entry, not through a
  development-board ground trace.
- VNH inputs have external pull-downs so reset cannot start an actuator.
- D-M9N and D-M9P sensors may be powered from 3.3 V when that voltage has been
  verified on the exact sensors. D-M9N inputs use pull-ups; D-M9P inputs use
  pull-downs. A three-bit polarity mask is stored in the cabinet EEPROM, so the
  replaceable STM32 firmware remains universal. Do not power a sensor output from
  5 V when it is connected directly to an STM32 input.
- CAP1188 `ADDR_COMM` is tied to GND for normal 4-wire SPI mode.
- CAN uses 120 Ohm termination only at the two physical ends of the complete bus.
- The final carrier must include transient suppression and reverse-polarity protection.

## Power-good input

All ADC-capable pins are already allocated, so 12 V is monitored by a comparator or
supervisor on the carrier. Its open-drain output drives PC13 low when motor supply is
below the safe threshold. This avoids an unsafe analog pin conflict with current sense,
SPI or UART.

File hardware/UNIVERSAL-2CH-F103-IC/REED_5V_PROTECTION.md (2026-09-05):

# Reed sensor 5 V input protection

## Connectors

`J201` is the open-position sensor and `J202` is the closed-position sensor.
Both connectors use the same pin order printed on the front silkscreen:

1. `5V`
2. `SIG`
3. `GND`

The intended sensors are NPN D-M9N units. The firmware-selectable reed polarity
and STM32 internal pull resistor remain unchanged.

## Accidental PNP connection protection

`R290` and `R291` are 4.7 kOhm series resistors between the two sensor signal
pins and STM32 pins PB0/PB1. If a 5 V PNP D-M9P output is connected by mistake,
the resistor limits the current into the STM32 input clamp to approximately
0.3 mA. This protects against an accidental 5 V PNP output; it does not protect
the signal input from 12 V, reversed power, or arbitrary field wiring faults.

R290 and R291 are top-side SMD parts. The September 2026 repair also moves C340
to the top side. The historical PCBA CPL files do not contain this change.
R290 and R291 were kept on top because the corresponding
bottom-side areas contain power copper and cannot accept the parts without a
major reroute.

## Required assembly wires

Three insulated wire links must be installed after PCB assembly:

- `TP290` to `JP290` (`J220.6`): CAP1188 3.3 V supply link. `TP290` is the
  0.6 mm exposed SMD pad on the bottom side. `JP290` is the 0.6 mm plated hole
  near the front-side `WIRE TP290 -> JP290` marking.
- `C280+` to `J280B`: existing 5 V hold-up capacitor supply link.
- `D230.1` (cathode, protected 12 V) to `C270.1` (positive supply): feeds
  U270 and R270 after reverse-polarity protection. These are existing SMD pads,
  not new through-hole terminals. Do not connect this wire to D230.2.

Use insulated copper wire around 0.2-0.35 mm2. Thin PTFE-insulated wire is also
acceptable for these low-current logic supplies when it is mechanically fixed
and strain relieved.

Do not power the board before all three links have been installed and checked for
continuity and shorts to GND.

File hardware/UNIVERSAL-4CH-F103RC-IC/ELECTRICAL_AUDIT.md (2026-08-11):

# Electrical audit

Audit target: `kicad/UNIVERSAL-4CH-F103RC-IC.kicad_pcb`.

## Voltage domains

| Domain | Nominal voltage | Source | Loads |
| --- | ---: | --- | --- |
| Motor channel 1..4 | 12 V | Pin 1 of each J1..J4 harness | VNH5019A-E and local bulk capacitor |
| Logic input | 12 V | J230 through F230, D230 and D231 | MP1584 and TLV6700 |
| Logic rail | 5 V | Soldered MP1584 module | Reed sensors and hold-up diode |
| Hold-up rail | about 4.7 V | D280 from 5 V | C280 and AMS1117 input |
| Logic | 3.3 V | AMS1117 through R2301 | STM32, CAP1188, EEPROM and CAN module |

All fitted capacitor voltage ratings exceed their nominal rail. The 12 V
logic path uses 25 V or 50 V ceramics and a 50 V bulk capacitor. VNH channel
bulk capacitors are 35 V and local ceramics are 50 V. The 5 V and hold-up
rails use 10 V capacitors.

## Mandatory assembly conditions

- Fit the insulated wire from `C280+` to `J280B`. It is the designed connection
  between the isolated hold-up capacitor and the AMS1117 input. Without it the
  3.3 V rail is off.
- Supply motor power to pin 1 of every populated J1..J4 connector. These four
  motor feeds are separate from J230 and must be externally fused for 5 A per
  channel or less, selected to suit the actual actuator wiring.
- Fit R240 only at a physical end of the CAN trunk. Leave it DNP at intermediate
  nodes.
- Use 2 oz finished copper for the checked 5 A routing margin.

## Corrected issue

The former `S2_3V3` island feeding the channel 3 and 4 diagnostic pull-ups and
ADC clamps had no source. It is now merged and physically routed to `S1_3V3`.
The electrical audit fails if that legacy orphan net returns.

## Automated checks

```powershell
$py = 'C:\Users\Ezhik\AppData\Local\Programs\KiCad\10.0\bin\python.exe'
& $py tools\verify_universal4ch_f103rc_board.py hardware\UNIVERSAL-4CH-F103RC-IC\kicad\UNIVERSAL-4CH-F103RC-IC.kicad_pcb
& $py tools\audit_universal4ch_f103rc_electrical.py hardware\UNIVERSAL-4CH-F103RC-IC\kicad\UNIVERSAL-4CH-F103RC-IC.kicad_pcb
& $py tools\audit_universal4ch_power_width.py hardware\UNIVERSAL-4CH-F103RC-IC\kicad\UNIVERSAL-4CH-F103RC-IC.kicad_pcb
python tools\verify_universal4ch_f103rc_firmware.py
```

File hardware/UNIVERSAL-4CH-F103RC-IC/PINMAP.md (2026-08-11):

# STM32F103RCT6 pin map

The controller uses the same CAN/UART protocol and universal cabinet
configuration model as the other STM32 nodes. Four motor channels are handled
locally by one LQFP64 MCU.

This is a separate compile-time hardware target of the universal source. It is
not pin-compatible with the compiled F103C8 two-channel target.

| Function | STM32 pin |
| --- | --- |
| VNH1 current | PA0 / ADC1_IN0 |
| VNH2 current | PA1 / ADC1_IN1 |
| VNH3 current | PA2 / ADC1_IN2 |
| VNH4 current | PA3 / ADC1_IN3 |
| CAP1188 CS | PA4 |
| CAP1188 SCK | PA5 / SPI1_SCK |
| CAP1188 MISO | PA6 / SPI1_MISO |
| CAP1188 MOSI | PA7 / SPI1_MOSI |
| VNH1 PWM | PA8 / TIM1_CH1 |
| VNH2 PWM | PA9 / TIM1_CH2 |
| VNH3 PWM | PA10 / TIM1_CH3 |
| VNH4 PWM | PA11 / TIM1_CH4 |
| SWDIO | PA13 |
| SWCLK | PA14 |
| VNH1 INA / INB | PB0 / PB1 |
| VNH2 INA / INB | PB10 / PB11 |
| VNH3 INA / INB | PB12 / PB13 |
| VNH4 INA / INB | PB14 / PB15 |
| CAN RX / TX | PB8 / PB9, CAN remap |
| Reed open | PC0 |
| Reed closed | PC1 |
| Reed in-place | PC2 |
| Power-good | PC3 |
| EEPROM CS | PC4 |
| CAP1188 IRQ | PC5 |
| VNH diagnostics 1..4 | PC6 / PC7 / PC8 / PC9 |
| CAP1188 reset | PC10 |
| HSE crystal | PD0 / PD1 |

BOOT0 and BOOT1 have dedicated 10 kohm pull-down resistors. SWD remains
available for programming and recovery.

The F103 CAN peripheral must use the PB8/PB9 remap. PA11 remains available as
TIM1_CH4 for actuator 4 PWM. CAP1188 and the 25LC256 share SPI1, with separate
chip-select signals on PA4 and PC4.

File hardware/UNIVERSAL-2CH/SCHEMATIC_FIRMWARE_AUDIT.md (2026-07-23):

# UNIVERSAL-2CH schematic and firmware audit

Audit target: the routed PCB, generated flat/multisheet schematics, and
`STM32_Universal_Actuator_Node`.

## Functional socket mapping

| Function | STM32 pin | MOD1 pad | PCB net |
|---|---:|---:|---|
| Current 1 / 2 | PA0 / PA1 | 20 / 10 | CH1/2_CURRENT_ADC |
| PWM 1 / 2 | PA8 / PA9 | 22 / 32 | CH1/2_PWM_MCU |
| INA 1 / 2 | PB14 / PB3 | 2 / 26 | CH1/2_INA_MCU |
| INB 1 / 2 | PB15 / PB4 | 12 / 36 | CH1/2_INB_MCU |
| DIAG 1 / 2 | PB5 / PB12 | 27 / 3 | CH1/2_DIAG |
| Reeds | PB0 / PB1 / PB8 | 6 / 5 / 38 | OPEN / CLOSED / IN_PLACE |
| CAP1188 CS / IRQ / RESET | PA4 / PB13 / PB9 | 18 / 13 / 29 | CAP_CS / IRQ / RESET |
| SPI SCK / MISO / MOSI | PA5 / PA6 / PA7 | 8 / 17 / 7 | CAP_SCK / MISO / MOSI |
| Carrier EEPROM CS | PA15 | 35 | EEPROM_CS |
| Power good | PC13 | 30 | POWER_GOOD |
| CAN RX / TX | PA11 / PA12 | 33 / 24 | S1_CAN_RX / S1_CAN_TX |
| SWDIO / SWCLK / NRST | PA13 / PA14 / NRST | 34 / 25 / 16 | service nets |

PA15, PB3, and PB4 are released from JTAG at startup with
`__HAL_AFIO_REMAP_SWJ_NOJTAG()` while SWD remains available.

The VNH5019A-E current-sense baseline is 5.7 mA per ADC count for the fitted
1 kOhm sense resistor and 12-bit 3.3 V ADC. The firmware default is 57/10.
Each assembled channel still requires a measured calibration under its real
mechanical load.

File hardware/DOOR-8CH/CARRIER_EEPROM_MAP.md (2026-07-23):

# Carrier SPI EEPROM data

The DOOR-8CH board uses an external SPI EEPROM on the carrier PCB so the
socketed STM32 modules remain universal. A replacement STM32 board only needs
the common firmware; cabinet identity stays on the carrier board.

## Device

Default part: `25LC256` in SOIC-8.

Compatible non-volatile SPI parts may be used later if they support the same
basic commands used by the firmware:

- `0x03` read;
- `0x02` page write;
- `0x05` read status;
- `0x06` write enable.

## Pinout

| EEPROM pin | Net | STM32 S1 |
| ---: | --- | --- |
| 1 `/CS` | `EEPROM_CS` with 10 kOhm pull-up | PA15 |
| 2 `SO` | `CAP_MISO` | PA6 |
| 3 `/WP` | `EEPROM_WP` with 10 kOhm pull-up | - |
| 4 `VSS` | `GND` | - |
| 5 `SI` | `CAP_MOSI` | PA7 |
| 6 `SCK` | `CAP_SCK` | PA5 |
| 7 `/HOLD` | `EEPROM_HOLD` with 10 kOhm pull-up | - |
| 8 `VCC` | `S1_3V3`, 100 nF nearby | - |

The EEPROM shares SPI with CAP1188. Its chip-select is separate from CAP1188.
`S1_3V3` is generated by the MASTER module from the diode-isolated hold-up rail,
so U250 remains powered long enough to save an outage record.

## Identity records at 0x0000 and 0x0020

The firmware structure is packed and little-endian. Two copies are maintained:
the current record and a rollback record. A web reconfiguration is written to
the inactive address, read back and CRC-checked before its higher
`configRevision` makes it active. An interrupted write therefore leaves the
previous valid identity available at startup.

| Offset | Size | Field | Value |
| ---: | ---: | --- | --- |
| `0x00` | 4 | `magic` | `0x314E4957`, ASCII `WIN1` |
| `0x04` | 1 | `version` | `1` |
| `0x05` | 1 | `cabinetId` | CAN cabinet id, `0..63` |
| `0x06` | 1 | `objectType` | `0` window, `1` single door, `2` double door |
| `0x07` | 1 | `slaveCount` | `0` window, `1` single door, `3` double door |
| `0x08` | 2 | `configRevision` | incremented after each verified web reconfiguration |
| `0x0A` | 2 | `reserved` | reed polarity mask, see below |
| `0x0C` | 2 | `crc` | CRC-16/CCITT over this structure with `crc=0` |

## Address 0x0040 power-loss record

This packed record occupies one 64-byte EEPROM page. It is written only once
per detected outage and acknowledged after its CAN event is queued following a
successful restart.

| Offset | Size | Field | Value |
| ---: | ---: | --- | --- |
| `0x00` | 4 | `magic` | `0x31525750`, ASCII `PWR1` |
| `0x04` | 4 | `uptimeMs` | STM32 uptime when `POWER_GOOD` fell |
| `0x08` | 2 | `crc` | CRC-16/CCITT with this field set to zero |
| `0x0A` | 1 | `version` | `1` |
| `0x0B` | 1 | `pending` | `1` until reported after reboot |
| `0x0C` | 1 | `sequence` | increments for each saved outage |
| `0x0D` | 1 | `runState` | state immediately before shutdown |
| `0x0E` | 1 | `command` | active command immediately before shutdown |
| `0x0F` | 1 | `fault` | preceding fault code |
| `0x10` | 1 | `actuator` | preceding fault actuator index |
| `0x11` | 1 | `reserved` | zero |

## Reed polarity mask

`reserved` currently stores the D-M9 sensor polarity mask.

Bit value:

- `0` = active-low sensor, normal for D-M9N/NPN with STM32 pull-up;
- `1` = active-high sensor, use for D-M9P/PNP if wired for 3.3 V output.

Bit assignment:

| Bit | Sensor |
| ---: | --- |
| 0 | leaf A open |
| 1 | leaf A closed |
| 2 | leaf A in-place |
| 3 | leaf B open |
| 4 | leaf B closed |
| 5 | leaf B in-place |

For a single door or window only bits 0..2 are used. For a double door S1 uses
bits 0..2 and sends bits 3..5 to S2 over the internal UART.

## Default project images

The generator `tools/generate_carrier_eeprom_images.py` creates the default
images in `firmware_releases/carrier_eeprom/default_project/`:

| File | cabinetId | objectType | slaveCount | reed mask |
| --- | ---: | ---: | ---: | ---: |
| `cabinet_01_double_door.bin` | 1 | 2 | 3 | `0x00` |
| `cabinet_02_single_door_1.bin` | 2 | 1 | 1 | `0x00` |
| `cabinet_03_single_door_2.bin` | 3 | 1 | 1 | `0x00` |
| `cabinet_04_single_door_3.bin` | 4 | 1 | 1 | `0x00` |
| `cabinet_05_window.bin` | 5 | 0 | 0 | `0x00` |

Change only the reed mask if the installed D-M9 sensors are PNP/active-high.

## ESP32 backup and carrier replacement

ESP32 firmware build 9 keeps a CRC-protected backup for every configured
cabinet in its NVS partition. The backup is indexed by `cabinetId` and contains:

- cabinet number and displayed name;
- object type and actuator/slave count;
- D-M9 reed polarity mask;
- enabled CAP1188 channel mask;
- source MASTER STM32 UID and last confirmed carrier configuration revision.

The backup is refreshed after every successful web configuration and is also
created when ESP32 discovers an already configured cabinet known in its object
list.

To replace a complete carrier board:

1. Disconnect the old carrier from CAN and power.
2. Connect the new carrier with a blank EEPROM and universal STM32 firmware
   build 9 or newer.
3. In the web interface open settings, scan the CAN bus and select
   `Restore` for the unconfigured MASTER.
4. Enter the old cabinet number.

ESP32 refuses restoration while the old cabinet is online, when that CAN number
is used by another discovered controller, or when the target is already
configured. STM32 writes the identity to the inactive A/B slot, reads it back,
checks its CRC and only then confirms the operation. ESP32 then binds the saved
object to the new MASTER UID and sends the saved CAP1188 channel mask when the
new controller starts reporting status.

The power-loss record is deliberately not restored because it is a historical
event from the old board. Per-actuator speed calibration remains local to each
STM32 module and must be repeated after replacing STM32 modules, motor drivers
or actuators.

ESP32 firmware `v0.1.0-alpha.10` also includes all carrier EEPROM backup records
in the downloadable system settings file (`.wbackup`). Restoring that file on a
replacement ESP32 restores the cabinet table and its EEPROM backups together.
The file has a versioned header and CRC32; its size and every contained cabinet
record are validated before NVS is changed.

Firmware `v0.1.0-alpha.11` exports backup format V2, which additionally stores
the optional SLIDE-2CH pairings and sequence delays. V1 files from alpha.10
remain importable; automatic sliding is left disabled when restoring V1.

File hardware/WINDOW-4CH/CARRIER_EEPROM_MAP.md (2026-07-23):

# WINDOW-4CH carrier EEPROM

The 25LC256 on the carrier keeps both socketed STM32 modules universal. S1
reads the cabinet identity; S2 obtains its operating configuration over UART.

## Identity at 0x0000 and 0x0020

The two addresses form an A/B pair. Reconfiguration writes and verifies the
inactive copy first. The valid copy with the newest `configRevision` is loaded,
so loss of power during a write does not destroy the previous configuration.

| Offset | Size | Field | WINDOW-4CH value |
| ---: | ---: | --- | --- |
| `0x00` | 4 | magic | `0x314E4957` (`WIN1`) |
| `0x04` | 1 | version | `1` |
| `0x05` | 1 | cabinetId | unique CAN address, `0..63` |
| `0x06` | 1 | objectType | `0` for window |
| `0x07` | 1 | slaveCount | `0` for two actuators, `1` for four actuators |
| `0x08` | 2 | configRevision | incremented after each verified web reconfiguration |
| `0x0A` | 2 | reserved | D-M9 polarity mask |
| `0x0C` | 2 | crc | CRC-16/CCITT with this field zeroed |

Only reed polarity bits 0..2 are used: open, closed and in-place. A zero bit is
active-low D-M9N; a one bit is active-high D-M9P wired for a 3.3 V output.

## Power-loss record at 0x0040

The existing universal firmware uses the same 64-byte page and `PWR1` record
layout documented for `DOOR-8CH`. U250 is supplied from held `S1_3V3`, while
D280 and C280 keep S1 alive long enough to finish one protected EEPROM write.

## Replacement from the ESP32 backup

The ESP32 backup and restore procedure is shared with the eight-channel board.
After disconnecting the old carrier, discover the blank replacement in the web
interface, select `Restore` and enter the old cabinet number. The saved window
identity, actuator count, reed polarity, name and CAP1188 channel mask are
restored only after the STM32 has written, read back and CRC-checked its A/B
EEPROM record.

See `hardware/DOOR-8CH/CARRIER_EEPROM_MAP.md` for the complete safety checks and
backup contents. Speed calibration is intentionally repeated after replacing
STM32 modules, drivers or actuators.

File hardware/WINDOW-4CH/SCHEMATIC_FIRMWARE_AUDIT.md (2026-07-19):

# WINDOW-4CH schematic and firmware audit

Audit target: routed `WINDOW-4CH.kicad_pcb`, generated flat and multisheet
schematics, `STM32_Universal_Actuator_Node` v0.1.0-alpha.8 and
`ESP32_CC1101_CAN_Master` v0.1.0-alpha.7.

## Result

The schematic-to-PCB verifier found exactly 138 component references, 447
connected numbered pads and 60 intentionally blank pads in both representations.
PCB DRC reports zero violations and zero unconnected items. Schematic ERC
reports zero errors. Warnings are isolated reserve labels on the universal
STM32 pinout and do not represent PCB opens.

## Firmware pin agreement

| Function | Firmware pin | WINDOW-4CH net | Result |
| --- | --- | --- | --- |
| Local current 1/2 | PA0 / PA1 | odd/even `CHx_CURRENT_ADC` | OK |
| Local PWM 1/2 | PA8 / PA9 | odd/even `CHx_PWM_MCU` | OK |
| Local INA 1/2 | PB14 / PB3 | odd/even `CHx_INA_MCU` | OK |
| Local INB 1/2 | PB15 / PB4 | odd/even `CHx_INB_MCU` | OK |
| Local diagnostic 1/2 | PB5 / PB12 | odd/even `CHx_DIAG` | OK |
| Slot identity | PB2 / PA7 | S1/S2 carrier straps | OK |
| Reeds | PB0 / PB1 / PB8 | open / closed / in-place on S1 | OK |
| CAP1188 SPI | PA4 / PA5 / PA6 / PA7 | CS / SCK / MISO / MOSI on S1 | OK |
| CAP1188 control | PB13 / PB9 | IRQ / RESET on S1 | OK |
| Carrier EEPROM | PA15 plus shared SPI | `EEPROM_CS` | OK |
| STM32 CAN | PA11 / PA12 | CAN1 CRX / CTX on S1 | OK |
| S1 to S2 UART | PB7 / PB6 | S2 PB6 / PB7, crossed RX/TX | OK |
| Logic power monitor | PC13 | U270 open-drain `POWER_GOOD` | OK |

Each STM32 firmware instance controls exactly two local actuators. With S1 as
MASTER and S2 as slot-1 SLAVE, telemetry indices 0..3 and all four calibration
records are supported without a board-specific firmware build.

## Configuration finding

The existing two-actuator window remains in the ESP32 object table with no
SLAVE. ESP32 v0.1.0-alpha.7 adds each newly discovered cabinet as a separate
object and accepts 2, 4, 6 or 8 actuators. It derives the local SLAVE count as
0, 1, 2 or 3 respectively, so a WINDOW-4CH cabinet is stored as four actuators
with one SLAVE without replacing the two-actuator window.

CAP1188 is physically present on S1. Use enabled mask `0x07` for three sensors
or `0x0F` when the spare fourth input is fitted.

## Prototype checks still required

- Calibrate `CURRENT_MA_PER_ADC_COUNT_NUM/DEN` with a populated VNH5019 channel.
- Confirm the new 5 A default trip threshold with a calibrated current source
  before commissioning the 2.5 A actuators.
- Confirm UART reliability at 250 kbit/s over the actual short cabinet wiring.
- Verify the C280 power-fail write margin on the assembled carrier.

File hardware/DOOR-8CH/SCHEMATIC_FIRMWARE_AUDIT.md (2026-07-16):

# DOOR-8CH schematic and firmware audit

Audit target: routed `DOOR-8CH.kicad_pcb`, generated principle schematics,
`STM32_Universal_Actuator_Node` v0.1.0-alpha.7 and
`ESP32_CC1101_CAN_Master` v0.1.0-alpha.6.

## Result

The generated flat and multisheet schematics contain all 238 PCB references,
all numbered pads and the same net labels as the routed PCB. KiCad ERC reports
zero errors. The two remaining warnings are intentionally isolated optional
nets: the ESP32 GPIO9 learn-button input and the unused S1 PA7 slot-ID pull-up.

## Firmware pin agreement

| Function | Firmware pin | PCB connection | Result |
| --- | --- | --- | --- |
| Actuator current 1/2 | PA0 / PA1 | local odd/even `CHx_CURRENT_ADC` | OK |
| VNH PWM 1/2 | PA8 / PA9 | local odd/even `CHx_PWM_MCU` | OK |
| VNH INA 1/2 | PB14 / PB3 | local odd/even `CHx_INA_MCU` | OK |
| VNH INB 1/2 | PB15 / PB4 | local odd/even `CHx_INB_MCU` | OK |
| VNH diagnostic 1/2 | PB5 / PB12 | local odd/even `CHx_DIAG` | OK |
| Slot identity | PB2 / PA7 | S1-S4 carrier straps | OK |
| Reeds A/B | PB0 / PB1 / PB8 | open / closed / in-place | OK |
| CAP1188 SPI | PA4 / PA5 / PA6 / PA7 | CS / SCK / MISO / MOSI | OK |
| CAP1188 control | PB13 / PB9 | IRQ / RESET | OK |
| Cabinet EEPROM | PA15 plus shared SPI | `EEPROM_CS` | OK |
| STM32 CAN | PA11 / PA12 | CAN1 CRX / CTX | OK |
| Master UART 1 | PB7 / PB6 | S2 RX / TX link | OK |
| Master UART 2 | PA3 / PA2 | S3 RX / TX link | OK |
| Master UART 3 | PB11 / PB10 | S4 RX / TX link | OK |
| ESP32 CC1101 SPI | GPIO10-13 | CS / MOSI / SCK / MISO | OK |
| ESP32 CC1101 data | GPIO4 / GPIO5 | GDO0 / GDO2 | OK |
| ESP32 CAN | GPIO38 / GPIO39 | CAN2 CRX / CTX | OK |
| Logic power monitor | PC13 | `POWER_GOOD`, U270 open-drain output | OK |

## Power-fail implementation

U270 (`TLV6700DDCR`) monitors `LOGIC_12V_FUSED` through 226 kOhm / 10 kOhm.
Its two open-drain outputs are tied to `POWER_GOOD` and pulled up to `S1_3V3`.
The nominal thresholds are about 9.44 V rising and 9.31 V falling. D280
(`SS34`) isolates the MASTER 5 V input and C280 (4700 uF / 10 V, low ESR)
holds up S1 and U250 long enough for one EEPROM page write.

Firmware stops the local outputs and SLAVEs on the first low level, stores one
CRC-protected power-loss record in U250, then reports `PowerRecovered` over CAN
after the next boot. The ESP32 stores its 48-entry event ring in NVS, so the
web journal also survives an ESP32 restart.

The hold-up duration must still be measured on the populated prototype at the
highest MASTER-board current and lowest expected temperature. Do not release
production Gerbers until the EEPROM write completes reliably with margin.

The current-sense scale in `config.h` is still marked for calibration. Its
conversion constant and protection thresholds must be measured on a populated
VNH5019 channel before field commissioning.

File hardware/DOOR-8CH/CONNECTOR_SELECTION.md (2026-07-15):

# DOOR-8CH connector selection

## CAP1188 and reed sensors

The current PCB placement uses direct-wire spring terminals from the Phoenix
Contact PT 1.5 family:

| Connection | PCB terminal | Pitch | Quantity per universal PCB |
| --- | --- | ---: | ---: |
| CAP1188 CS1...CS8 twisted pairs | `PT 1,5/2-3,5-H` | 3.5 mm | 8 |
| D-M9N / D-M9P three-wire sensors | `PT 1,5/3-3,5-H` | 3.5 mm | 6 |
| Dedicated logic 12 V input | `PT 1,5/2-3,5-H` | 3.5 mm | 1 |
| CAN trunk input, CANH/CANL/GND/SHIELD | `PT 1,5/4-3,5-H` | 3.5 mm | 1 |

These are fixed push-in terminals, so no mating plug is required. Lower-cost
`KF350-2P` and `KF350-3P` parts may have the same 3.5 mm electrical pitch, but
their body and wire-entry geometry must be compared with the 1:1 PCB print
before substitution.

The motor and fused channel-power terminals remain 5.08 mm pitch and require a
separate >=10 A/contact selection. Do not substitute the 3.5 mm sensor terminals
into a motor-current position.

## MP1584 module

The carrier footprint is marked `MP1584_Fixed5V_Module_22.3x17mm`. It has four
oversized solder pads for `IN+`, `IN-`, `OUT+`, and `OUT-`. Check the purchased
module against the 1:1 print before fabrication because low-cost boards sold
under the same MP1584 name do not guarantee identical pad centres.

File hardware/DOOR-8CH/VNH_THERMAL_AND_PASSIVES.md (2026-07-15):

# VNH5019 thermal zones and mandatory passive parts

## Complete circuit per VNH5019A-E

Every populated VNH position has all of these fitted parts. None are optional
for normal operation.

| Function | Parts per VNH | Values |
| --- | ---: | --- |
| MCU input safe state | 3 pull-downs | 10 kOhm on PWM, INA, INB |
| MCU input protection | 3 series resistors | 100 Ohm on PWM, INA, INB |
| Bridge enable / fault readback | 1 pull-up | 4.7 kOhm to 3.3 V, shared by ENA/DIAGA and ENB/DIAGB |
| Current-sense enable | 1 pull-down | 10 kOhm from CS_DIS to GND |
| Current-sense load | 1 resistor | 1.00 kOhm, 1% from CS to GND |
| ADC input protection | 1 resistor + 1 dual diode | 10 kOhm series plus BAT54S clamps to 3.3 V and GND |
| ADC anti-noise filter | 1 capacitor | 100 nF at PA0/PA1 |
| VNH local power decoupling | 1 electrolytic + 1 ceramic | 470 uF / 35 V low-ESR + 100 nF / 50 V X7R |

The capacitor pair is placed directly beside the VNH power pins. The CS load
remains at the VNH. The 10 kOhm ADC resistor, BAT54S clamp and filter capacitor
sit in the low-noise area toward the corresponding STM32 socket. This preserves
useful resolution around the actuator's 2.5 A working current while limiting
current into the 3.3 V ADC if the VNH sense output rises toward its specified
5 V maximum.
Every component reference and value is present in the future KiCad schematic;
no firmware pull-up is used as a substitute for these safety parts.

## Thermal and heatsink footprint

Every VNH position receives:

- three large copper areas under the three exposed MultiPowerSO-30 slugs;
- dense thermal-via arrays from each slug area to the internal copper layers;
- a 30 x 30 mm component keepout around the package top;
- two **M3.2 NPTH** mounting holes outside the copper keepout, 26 mm
  centre-to-centre, one pair per VNH;
- a 6 mm diameter copper, solder-mask and component keepout around each hole;
- silkscreen polarity/insulation warning beside each heatsink area.

The holes are for a **top-side** small 20 x 20 x 10 mm finned aluminium
heatsink with a clamp or bracket. This is the preferred small-radiator position:
it has free airflow and avoids using the PCB as a structural thermal interface.
Fit a heatsink after thermal testing, or from the first build when the cabinet
has poor airflow.

The primary thermal path remains the specified large copper areas and thermal
via arrays. A bottom-side heatsink is an optional second path only when the
whole board can be pressed to a metal cabinet backplate through an insulating
thermal sheet. Do not use a bottom heatsink as a replacement for the copper and
via design.

## Electrical isolation rule

The VNH5019 exposed thermal slugs are not a common ground pad: they correspond
to `VCC`, `OUTA` and `OUTB`. A metal heatsink must therefore never touch the
package directly or bridge any slug copper areas.

Use one electrically insulating, thermally conductive pad (silicone/Sil-Pad or
Kapton thermal pad, 0.2 to 0.5 mm) between the VNH package and the top
heatsink. Use nylon M3 screws and spacers, or a mechanically isolated bracket.
Check with a multimeter that the heatsink has no continuity to VCC, OUTA, OUTB
or GND before powering the board.

The source for the exposed-pad electrical functions and thermal layout is the
[ST VNH5019A-E data sheet](https://www.st.com/resource/en/datasheet/vnh5019a-e.pdf).

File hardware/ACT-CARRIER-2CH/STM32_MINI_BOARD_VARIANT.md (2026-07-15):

# Required STM32 mini-board variant

## Selected module

Use the compact `STM32F103C8T6 mini` module shown in the supplier diagram. It
has two 1x15, 2.54 mm pin rows, a USB-C connector and a selectable USB/UART
implementation.

The supplied front-and-back photos match the selected revision: CH340 is fitted
on the back, the main HSE crystal is fitted, and no separate 32.768 kHz LSE
crystal is visible. This makes the photographed revision the reference module
for the first carrier layout.

## Mandatory order / assembly option

Order the board in **UART mode**:

- the CH340 USB-UART bridge is fitted;
- the board's R4 and R5 UART selection links are fitted;
- the alternative native-USB path is not fitted.

The supplier describes USB and UART as mutually exclusive Type-C functions. This
choice is mandatory because native USB uses `PA11` and `PA12`, while a MASTER
carrier needs those pins for bxCAN. The UART bridge normally connects to PA9 and
PA10. PA9 remains usable as the second 20 kHz PWM output because the CH340 RX
input is high impedance; PA10 is not used by the actuator firmware.

All replacement modules must be bought in this same configuration. It preserves
the project's "any STM32 board can replace any STM32 board" repair rule.

## Carrier footprint

The carrier uses four 1x10 female sockets. The module has two parallel pin
rows on each long side, as visible on both the supplier drawing and the
front/back photographs:

| Parameter | Value |
| --- | --- |
| Contacts | 4 rows x 10, 40 contacts total |
| Contact pitch along row | 2.54 mm |
| Outer-row centre-to-centre spacing | 20.32 mm |
| Spacing within each two-row side | 2.54 mm |
| Nominal module envelope | 32 x 22.86 mm |
| Mounting | Socketed; USB-C must face a board edge for service access |

The KiCad footprint is one indivisible 4x10 module footprint, not four
independently positioned connector references. Before Gerber release, compare
it with one physical purchased board using a 1:1 print. Low-cost listings
sometimes change the USB-C daughter layout or fit an LSE crystal without
changing the listing photo.

## LSE and slot straps

The board exposes PC14 and PC15 and shows optional LSE circuitry. Purchase the
version with the LSE crystal **not fitted**, otherwise PC14/PC15 cannot provide
the two carrier `SLOT_ID` straps. The supplied photo appears to meet this rule.
Before PCB release, confirm it with a continuity meter on one physical module;
listing photos are not a substitute for that electrical check.

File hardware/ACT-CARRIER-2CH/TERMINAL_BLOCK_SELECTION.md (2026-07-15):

# Terminal block selection

## Actuator outputs J2 and J3

Use a two-position, through-hole, vertical screw terminal with **5.08 mm pitch**.

**Primary part:** `Phoenix Contact MKDS 1,5/ 2-5,08`, order number `1715721`.
It is rated for 17.5 A, accepts a nominal 1.5 mm2 conductor and uses a screw
connection. This is comfortably above the 5 A actuator design current. [Phoenix
Contact data](https://www.phoenixcontact.com/en-gb/products/printed-circuit-board-terminal-mkds-15-2-508-1715721?type=pdf)

**Search terms for an available compatible substitute:**

```text
KF2EDG 5.08-2P straight screw terminal 15A 1.5mm2
DG301-5.08-02P vertical PCB screw terminal 15A
```

Only use an alternative if all of these match:

- 5.08 mm pin pitch;
- two positions, through-hole, vertical/straight cable entry;
- at least 10 A continuous rating per contact;
- accepts at least 1.0 mm2 stranded actuator wire;
- actual pin diameter and body outline checked against the carrier footprint
  before ordering PCB fabrication.

Use ferrules on stranded wires. Do not use 3.5 mm-pitch signal terminals,
spring terminals intended for Dupont wire, or pluggable header/socket pairs in
the actuator-current path.

## Carrier power input J1

Use the same 5.08 mm family in a four-position body: `MKDS 1,5/ 4-5,08` or a
dimensionally compatible `KF2EDG 5.08-4P` straight screw terminal. Pin order is
`FUSED_12V_CH1`, `GND`, `FUSED_12V_CH2`, `GND`. The two positive pins remain
separate all the way to U1 and U2 so the two 7.5 A fuses remain independent.

## Other low-current connectors

Use locking JST-XH or 3.81/5.08 mm screw terminals for logic, UART, sensors and
CAN. They are deliberately separate from motor terminals and are never rated as
actuator connectors.

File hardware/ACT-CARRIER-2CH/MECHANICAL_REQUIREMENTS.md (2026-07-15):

# ACT-CARRIER-2CH v0.1 mechanical requirements

## Required size before layout

The target outline is provisionally **160 x 100 mm maximum**. This is a design
envelope, not a final PCB size. It provides two separated 45 x 55 mm thermal
zones for VNH5019A-E, a central STM32 socket zone and a connector edge.

The final outline is set only after the exact terminal blocks and the STM32 mini
module are measured. Do not order a PCB from this provisional envelope.

## Intended top-side arrangement

```text
  actuator 1 terminal       actuator 2 terminal
          |                         |
      [ VNH U1 ]               [ VNH U2 ]
      [ 470uF ]                [ 470uF ]

  power input  --  STM32 mini socket  --  MASTER / sensor headers
                      SWD nearby
```

The motor terminals and VNH packages are kept on one long board edge so their
high-current copper stays out of the sensor and CAN connector region.

## Copper and assembly constraints

- Four layer board, 1.6 mm FR-4, 2 oz copper on top and bottom.
- ENIG finish is preferred for MultiPowerSO-30 assembly and exposed-pad quality.
- VNH5019A-E requires stencil and reflow or professional hot-air assembly; it
  is not a reliable hand-solder-only package.
- Use M3 mounting holes in four corners plus at least two holes near the VNH
  thermal zones if the enclosure allows it.
- Keep a 5 mm component-free keepout around screw terminals for ferrules and a
  screwdriver.
- The board needs airflow or contact with a metal cabinet backplate only after
  a thermal test demonstrates the need; do not electrically bond any VNH slug
  to the enclosure.

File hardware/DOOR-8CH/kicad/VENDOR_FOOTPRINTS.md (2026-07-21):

# Vendor and photo-derived footprints

- `ESP32-S3-DevKitC.kicad_mod` is adapted to the photographed YD ESP32-S3
  N16R8 dual-USB-C board: 44 pins, 2.54 mm pitch and 25.40 mm row spacing.
- `CAP1188_Adafruit1602_Module_2x13.kicad_mod` uses the exact outline, header
  and mounting-hole coordinates from Adafruit's official product 1602 Eagle
  board. The purchased blue module shown in the project photograph matches
  this board geometry.
- `SN65HVD230_Module_14.5x16.1mm_1x06.kicad_mod` is derived from the supplied
  listing photograph, which explicitly gives 14.5 x 16.1 mm.
- `CC1101_433MHz_Module_28x15mm_2x04.kicad_mod` is derived from the supplied
  listing photograph, which explicitly gives 28 x 15 mm and a 2x4 header.

All photo-derived footprints still require a 1:1 print check against one
physical purchased module before fabrication.

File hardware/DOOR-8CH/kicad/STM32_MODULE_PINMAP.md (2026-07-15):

# STM32F103C8T6 mini CH340 module pin map

This table is derived from the supplied photographs of the exact black
MuLuoxing module. The view is from the component side with USB-C at the top.
Pad numbers match `STM32F103C8T6_Mini_CH340_4x10.kicad_mod`.

| Left outer | Signal | Left inner | Signal | Right inner | Signal | Right outer | Signal |
| ---: | --- | ---: | --- | ---: | --- | ---: | --- |
| 1 | GND | 11 | 3V3 | 21 | 5V | 31 | GND |
| 2 | PB14 | 12 | PB15 | 22 | PA8 | 32 | PA9 |
| 3 | PB12 | 13 | PB13 | 23 | PA10 | 33 | PA11 |
| 4 | PB10 | 14 | PB11 | 24 | PA12 | 34 | PA13/SWDIO |
| 5 | PB1 | 15 | PB2/BOOT1 | 25 | PA14/SWCLK | 35 | PA15 |
| 6 | PB0 | 16 | NRST | 26 | PB3 | 36 | PB4 |
| 7 | PA7 | 17 | PA6 | 27 | PB5 | 37 | PB6 |
| 8 | PA5 | 18 | PA4 | 28 | PB7 | 38 | PB8 |
| 9 | PA3 | 19 | PA2 | 29 | PB9 | 39 | VERIFY ON MODULE |
| 10 | PA1 | 20 | PA0 | 30 | PC13 | 40 | VBAT |

Pad 39 is not legible enough in the listing photograph to release to copper.
It is deliberately unused. Confirm it by continuity measurement against the
STM32 package before a fabrication release.

## Slot identity straps

The photographed module does not expose both PC14 and PC15, so those pins must
not be used for slot identity. The carrier samples PB2 and PA7 at reset, before
initialising SPI. Both inputs have pull-ups; a fitted 0 Ohm link codes a zero by
connecting the corresponding input to GND.

| Slot | PB2 strap | PA7 strap | Firmware role |
| --- | --- | --- | --- |
| S1 | open | open | MASTER |
| S2 | fitted | open | SLAVE 1 |
| S3 | open | fitted | SLAVE 2 |
| S4 | fitted | fitted | SLAVE 3 |

PA7 is reused as CAP1188 SPI MOSI only in S1. S2-S4 never initialise the
CAP1188 bus, so their PA7 strap cannot conflict with an active peripheral.
PB2 is BOOT1 on the MCU; BOOT0 remains pulled low on the module for normal
Flash boot, therefore the carrier strap does not alter normal startup.

Before ordering boards, print the footprint at 1:1 and verify row spacing,
orientation, pad 1, 5 V, both GND pins and pad 39 on a physical module.

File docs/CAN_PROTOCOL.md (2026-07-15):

# CAN and local UART protocol

Protocol version: 1. Classic CAN 2.0B, standard 11-bit identifiers, 500 kbit/s.

## CAN identifiers

| Range | Direction | Purpose |
| --- | --- | --- |
| 0x100-0x13F | ESP32 to cabinet | command and heartbeat |
| 0x180-0x1BF | cabinet to ESP32 | aggregate state |
| 0x200-0x23F | cabinet to ESP32 | reeds, CAP1188 and power status |
| 0x280-0x37F | cabinet to ESP32 | actuator telemetry, four frames per cabinet |
| 0x380-0x3BF | cabinet to ESP32 | asynchronous fault/event |
| 0x3C0-0x3FF | ESP32 to cabinet | configuration fragments |
| 0x700 | ESP32 to all | discovery request |
| 0x740-0x77F | cabinet to ESP32 | discovery response |
| 0x7C0 | ESP32 to unconfigured master | provision carrier identity by UID hash |

For cabinet `N`, actuator telemetry frame `0x280 + N*4 + slot` contains the two
actuators controlled by that STM32. Slot 0 is master, slots 1-3 are local slaves.

Commands carry a sequence counter. A motor command is accepted only after a recent
ARM command or with an explicit armed flag. While moving, ESP32 repeats the active
command as a heartbeat. Loss of a valid command for 300 ms stops the cabinet.

The command set includes open, close, stop, clear fault, separate open/close
calibration and calibration reset. A full calibration cycle is coordinated by
ESP32 as two position-aware single-direction calibration commands. Provisioning
stores cabinet ID, object type, slave count and the three-bit D-M9P polarity mask.

CAP1188 configuration is stored per cabinet as an eight-bit enabled-channel mask.
The web interface edits individual CS1...CS8 switches and also displays the active
channel count. ESP32 sends the mask through the configuration range; the cabinet
MASTER writes it to CAP1188 Sensor Input Enable and Interrupt Enable, persists it,
and recalibrates all newly enabled channels. A mask of zero disables touch sensing
and must be shown as a deliberate maintenance state in the browser.

## Local UART

Master-to-slave links use 250000 8N1 and a binary frame:

```text
A5 | type | payload_length | sequence | payload | CRC16-CCITT
```

CRC covers `type`, `length`, `sequence` and payload. Each slave is point-to-point,
so there is no bus address or collision arbitration. All slaves use the same physical
PB6/PB7 UART pins; the carrier connects that pair to the corresponding master USART.

## Telemetry rate

- moving/calibrating: 10 Hz;
- idle: 1 Hz;
- fault events: immediate plus normal status;
- recommended capacity: 32 cabinets per 500 kbit/s segment;
- firmware table capacity on ESP32: 64 objects.

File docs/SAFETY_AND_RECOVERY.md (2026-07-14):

# Safety and recovery behaviour

## Startup and power recovery

VNH PWM and direction outputs are forced off before communication starts. A board
never resumes a command that was active before reset. After boot it requires valid
configuration, a fresh ARM and a new movement command.

If power fails during travel, position becomes unknown unless a definitive external
position sensor is active. The next movement must home to a known end position under
current, timeout and edge protection. Automatic movement after power restoration is
disabled by default.

## End-stop detection

Internal actuator end switches remove motor current. Firmware accepts this as a valid
end stop only when:

- normal current was observed after startup;
- minimum travel time has elapsed;
- current remains below the calibrated zero threshold for the confirmation interval;
- external position sensors do not contradict the result.

Early loss of current is reported as disconnected actuator, not as a successful end stop.

## Calibration

Opening and closing are calibrated independently. During a full stroke every channel
records the interval from motor start to confirmed current disappearance. The slowest
channel remains at maximum permitted PWM and faster channels are reduced toward the
same total travel time, never below the configured minimum torque PWM.

Only complete, fault-free strokes are eligible for adaptation. Edge activation,
overcurrent, manual stop, sensor conflict or communication loss discards the sample.
Calibration records use CRC and are committed only after a complete pass.

Without individual position feedback this aligns total stroke time, not exact position
at every point. Mechanisms that cannot tolerate transient skew require encoders, Hall
sensors or potentiometers on every actuator.

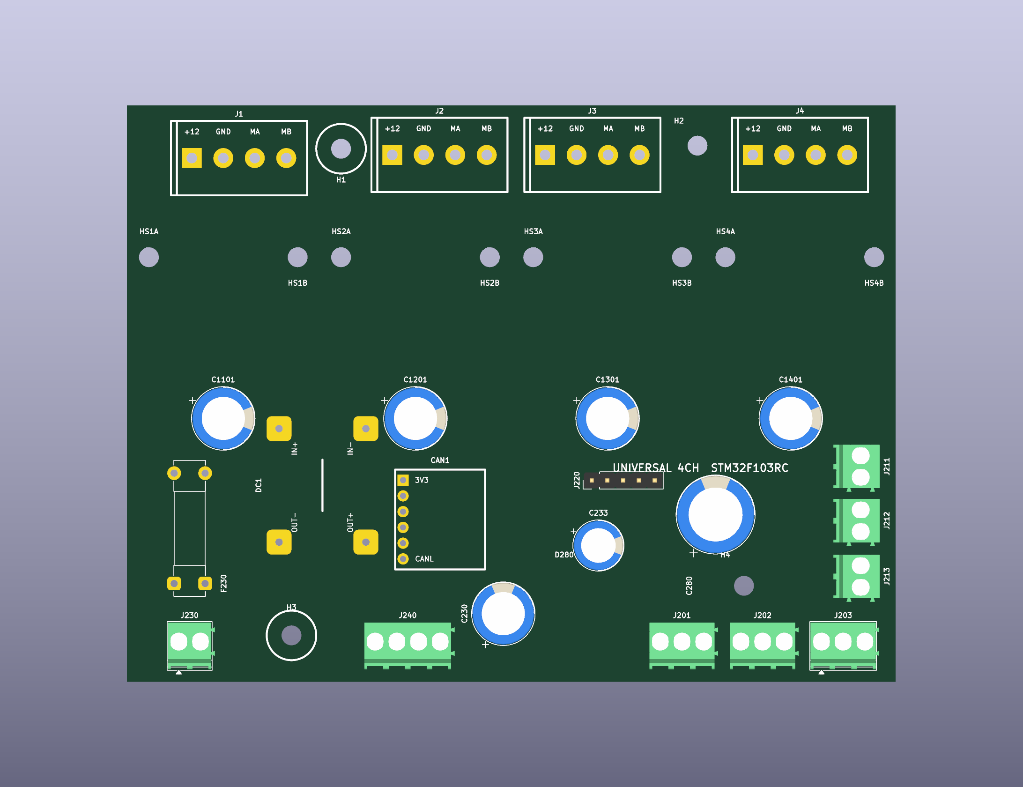
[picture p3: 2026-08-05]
hardware/UNIVERSAL-4CH-F103RC-IC/renders/UNIVERSAL-4CH-F103RC-IC-top.png

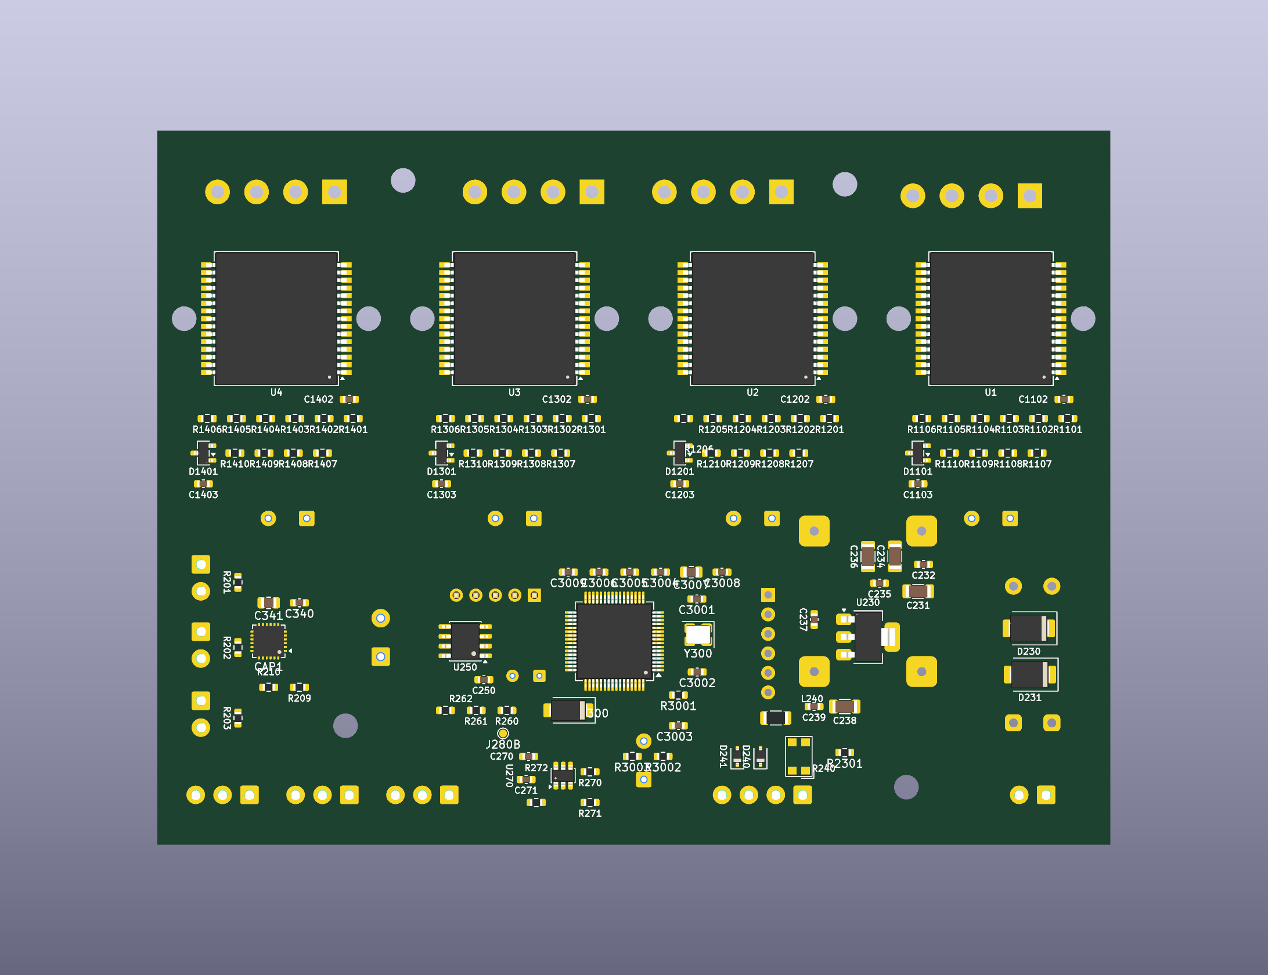
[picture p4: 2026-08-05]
hardware/UNIVERSAL-4CH-F103RC-IC/renders/UNIVERSAL-4CH-F103RC-IC-bottom.png

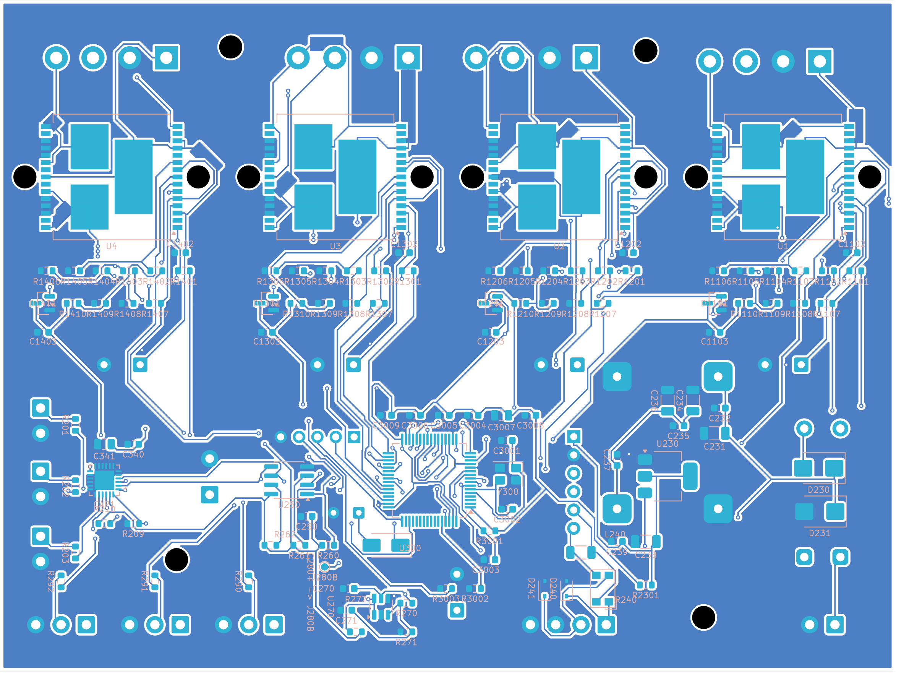
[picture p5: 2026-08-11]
hardware/UNIVERSAL-4CH-F103RC-IC/renders/UNIVERSAL-4CH-F103RC-IC-final-bottom.png

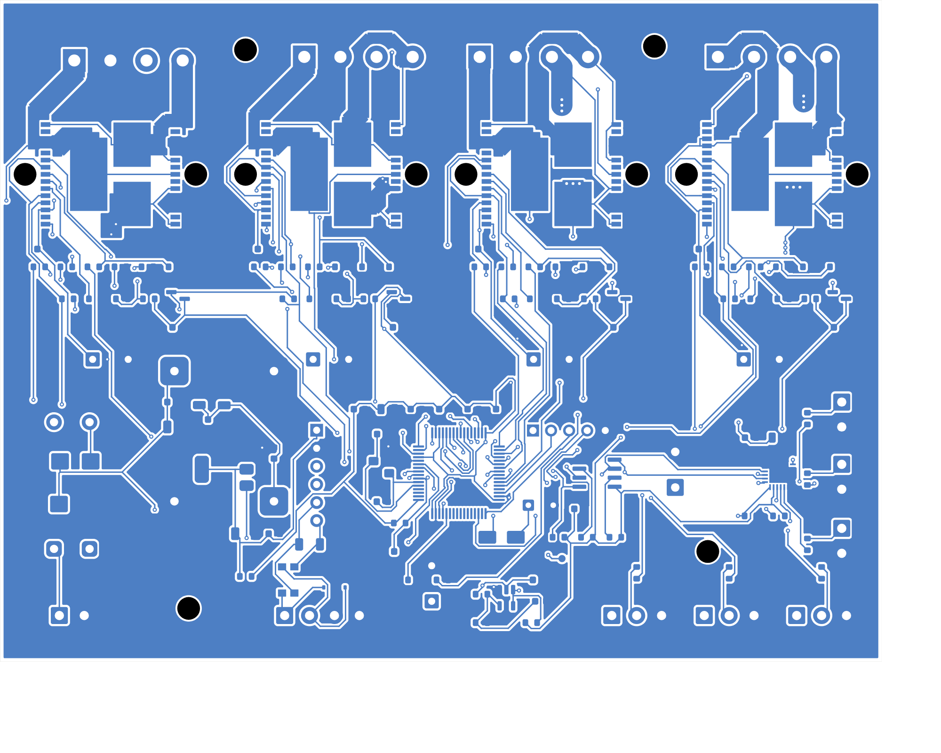
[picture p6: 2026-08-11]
hardware/UNIVERSAL-4CH-F103RC-IC/renders/UNIVERSAL-4CH-F103RC-IC-power-bottom.png

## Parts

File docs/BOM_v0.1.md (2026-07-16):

# BOM v0.1 - 22 actuator system

## Scope and assumptions

This bill of materials covers these objects:

| Object | Objects | Actuators per object | Total actuators | STM32 boards |
| --- | ---: | ---: | ---: | ---: |
| Double door | 1 | 8 | 8 | 4 |
| Single door | 3 | 4 | 12 | 6 |
| Window | 1 | 2 | 2 | 1 |
| **Total** | **5** | - | **22** | **11** |

One STM32 controls two VNH5019A-E channels. Each physical object uses one universal DOOR-8CH PCB with up to four STM32/VNH two-channel slots. Only slot 1 (MASTER) is connected to CAN; UART connections to the other slots are internal PCB tracks, not external cables.

This is a low-voltage 12 V DC design. Do not connect mains voltage to any board, signal connector or ESP32 input.

## Design current basis

The measured maximum actuator current is 2.5 A. This design uses a two-times reserve,
therefore every actuator channel is designed and protected for **5 A**. VNH5019 carrier
thermal design nevertheless keeps copper and heatsinking margin for a 10 A continuous
channel, so 5 A operation is not at the edge of the board capability.

| Cabinet | Actuators moving together | Design current | Recommended 12 V supply | Main fuse |
| --- | ---: | ---: | ---: | ---: |
| Double door | 8 | 40 A | 12 V, 50 A minimum | 50 A slow-blow / automotive blade |
| Each single door | 4 | 20 A | 12 V, 25 A minimum | 25 A slow-blow / automotive blade |
| Window | 2 | 10 A | 12 V, 15 A minimum | 15 A slow-blow / automotive blade |

Use a **7.5 A slow-blow or automotive blade fuse** per actuator channel. It is above the
5 A design current so brief startup current does not nuisance-trip it, while still protecting
the VNH channel and cable. This value must be confirmed once with one fully assembled
mechanism.

## Main modules

| Item | Quantity | Notes |
| --- | ---: | --- |
| ESP32-S3 N16R8 | 1 | Central controller, socketed directly on the double-door DOOR-8CH board. |
| CC1101, 433 MHz, 3.3 V module | 1 | Socketed directly on the double-door DOOR-8CH board. Include an antenna matched for 433 MHz. |
| STM32F103C8T6 mini board | 11 | Same firmware on every board. Buy 1 spare. |
| Universal DOOR-8CH PCB | 5 | One board per physical object. It has four two-channel slots; populate 4/2/1 slots for double door/single door/window. |
| VNH5019A-E IC | 22 | Two ICs in every populated two-channel slot. Buy at least 4 spare ICs from a traceable supplier. |
| VNH heatsink mounting provision | 22 zones | Two M3.2 **NPTH** holes at 26 mm centres, each with 6 mm copper/solder-mask keepout, plus a 30 x 30 mm top-side keepout per VNH. |
| Optional VNH heatsink | 22 maximum | 20 x 20 x 10 mm finned aluminium, fit after thermal test or in poorly ventilated cabinets. |
| Electrically insulating thermal pad | 22 maximum | Silicone/Sil-Pad or Kapton thermal pad, 0.2 to 0.5 mm; mandatory when a VNH heatsink is fitted. |
| Nylon M3 screw and spacer set | 22 maximum | One set per optional VNH heatsink; avoids electrical connection to the live thermal slugs. |
| CAP1188, SPI-capable breakout | 5 | One per physical object, including the window. All eight channels are routed to field connectors. |
| D-M9N / D-M9P reed sensor | 18 recommended, 17 minimum | Three per single door, six on the double door (three per leaf), and two for the window. Add the eighteenth sensor when the window also needs its third position. |
| 25LC256-I/P or 25LC256-I/SN SPI EEPROM | 5 | One in S1 MASTER zone of each DOOR-8CH board. SLAVE slots receive configuration from S1 over internal UART. |
| SN65HVD230, 3.3 V CAN transceiver module | 5 | Socketed in the S1 MASTER zone of every DOOR-8CH board. SLAVE STM32 slots use only internal UART. |
| SN65HVD230, 3.3 V CAN transceiver module | 1 | Socketed in the ESP32 zone of the double-door board. |
| 12 V to 5 V DC/DC converter, **MP1584 5 V module** | 5 + 2 spare | Plugs or solders directly to the DOOR-8CH PCB. Fit the fixed 5 V version; its actual 5 V load is below 1 A per cabinet. The double-door cabinet also powers the ESP32. |
| 12 V actuator power supply | 5 or 1 central supply | Size from actual actuator current as described below. Separate cabinet supplies are preferred for easier fault isolation. |
| SWD programmer, ST-Link V2 or V3 | 1 | For STM32 commissioning and recovery. |

VNH5019A-E is an active ST product with 3 V CMOS-compatible inputs, current sense and PWM operation up to 20 kHz. It is used as a bare IC on the custom DOOR-8CH board, so the CS scaling and 3.3 V ADC protection are defined by our own schematic rather than by an unknown breakout board. [ST product page](https://www.st.com/en/motor-drivers/vnh5019a-e.html)

## Cabinet allocation

| Cabinet | STM32 MASTER | STM32 SLAVE | VNH5019A-E | CAP1188 | Reeds | Local UART links |
| --- | ---: | ---: | ---: | ---: | ---: | ---: |
| Double door | 1 | 3 | 8 | 1 | 6 | 3 |
| Single door 1 | 1 | 1 | 4 | 1 | 3 | 1 |
| Single door 2 | 1 | 1 | 4 | 1 | 3 | 1 |
| Single door 3 | 1 | 1 | 4 | 1 | 3 | 1 |
| Window | 1 | 0 | 2 | 1 | 2 minimum, 3 recommended | 0 |
| **Total** | **5** | **6** | **22** | **5** | **17 minimum, 18 recommended** | **6** |

## One populated two-actuator slot: mandatory passive parts

Quantities in this table are **per populated two-actuator slot**. There are 11 populated slots across five DOOR-8CH boards.

| Reference / purpose | Component and nominal | Per populated slot | Total for 11 slots |
| --- | --- | ---: | ---: |
| PWM, INA and INB safe state | 10 kOhm, 1%, 0.125 W pull-down | 6 | 66 |
| PWM, INA and INB series protection | 100 Ohm, 0.125 W | 6 | 66 |
| VNH DIAG pull-up | 4.7 kOhm, 1%, 0.125 W to **3.3 V** | 2 | 22 |
| VNH supply bulk capacitor | 470 uF, **35 V**, low-ESR electrolytic, >=105 C | 2 | 22 |
| VNH local ceramic capacitor | 100 nF, 50 V, X7R | 2 | 22 |
| VNH CS load resistor | 1.00 kOhm, 1%, 0.125 W from CS to GND | 2 | 22 |
| VNH CS ADC divider | 68 kOhm upper + 100 kOhm lower, both 1%, 0.125 W | 2 + 2 | 22 + 22 |
| VNH CS ADC filter | 1 kOhm series plus 100 nF, 16 V, X7R at PA0/PA1 | 2 + 2 | 22 + 22 |
| VNH CS_DIS default | 10 kOhm, 1%, 0.125 W pull-down to GND | 2 | 22 |
| Slot 3.3 V bulk decoupling | 10 uF, 10 V, X5R/X7R | 1 | 11 |
| Carrier 3.3 V local decoupling | 100 nF, 16 V, X7R; near LDO and digital loads | 4 | 44 |

## Shared DOOR-8CH board parts

| Purpose | Component and nominal | Per board | Total for 5 boards |
| --- | --- | ---: | ---: |
| Board 3.3 V LDO | AP2112K-3.3 or equivalent, >=300 mA, SOT-23-5 | 1 | 5 |
| 3.3 V LDO bulk decoupling | 10 uF, 10 V, X5R/X7R; one at input and one at output | 2 | 10 |
| 12 V window supervisor | TLV6700DDCR, SOT-23-6, dual open-drain output | 1 | 5 |
| 12 V monitor divider | 226 kOhm upper + 10 kOhm lower, both 1%, 0.125 W | 1 + 1 | 5 + 5 |
| Supervisor supply and sense filters | 100 nF, 25 V, X7R | 2 | 10 |
| PC13 pull-up | 10 kOhm, 1%, 0.125 W to `S1_3V3` | 1 | 5 |
| MASTER hold-up diode | SS34, 3 A / 40 V Schottky | 1 | 5 |
| MASTER hold-up capacitor | 4700 uF, 10 V, low ESR, radial | 1 | 5 |

The `226 kOhm / 10 kOhm` divider and TLV6700 400 mV reference give nominal thresholds of approximately 9.44 V rising and 9.31 V falling using the device's internal hysteresis. Fit this circuit once per DOOR-8CH board. Verify the thresholds and C280 hold-up time on a populated board before enabling field operation.

For each VNH5019A-E, tie its two open-drain `DIAG/EN` pins into the one diagnostic node for that actuator, use the listed 4.7 kOhm pull-up and route that node to PB5 or PB12. This enables both bridge legs and lets either diagnostic pull the STM32 input low.

## MASTER-slot CAN parts only

These parts are fitted only beside slot S1 on the five DOOR-8CH boards. A failed MASTER STM32 is replaced by inserting the same spare STM32 board into slot S1, so the spare board itself does not need a CAN transceiver.

| Purpose | Component and nominal | Per S1 MASTER zone | Total |
| --- | --- | ---: | ---: |
| CAN module socket | 1x6, 2.54 mm female header for SN65HVD230 | 1 | 5 |
| CAN module 3.3 V bypass | 100 nF, 16 V, X7R + 1 uF, 16 V, X7R | 1 + 1 | 5 + 5 |
| CAN TX series resistor | 47 Ohm, 0.125 W | 1 | 5 |
| EEPROM | 25LC256-I/P or 25LC256-I/SN | 1 | 5 |
| EEPROM VCC decoupling | 100 nF, 16 V, X7R | 1 | 5 |
| EEPROM /WP and /HOLD | 10 kOhm, 1%, 0.125 W pull-up to 3.3 V | 2 | 10 |
| EEPROM CS default inactive | 10 kOhm, 1%, 0.125 W pull-up to 3.3 V | 1 | 5 |

## ESP32 CAN and radio interface parts

The ESP32 is in the double-door cabinet and is connected internally to the same CAN trunk as that cabinet's MASTER. It is a separate CAN node, therefore its transceiver needs its own local decoupling even though it does not need a second external cabinet connector.

| Purpose | Component and nominal | Quantity |
| --- | --- | ---: |
| ESP32 CAN module socket | 1x6, 2.54 mm female header for SN65HVD230 | 1 |
| ESP32 CAN module 3.3 V bypass | 100 nF, 16 V, X7R + 1 uF, 16 V, X7R | 1 + 1 |
| ESP32 CAN TX series resistor | 47 Ohm, 0.125 W | 1 |
| CC1101 supply bypass at its connector | 100 nF, 16 V, X7R + 10 uF, 10 V, X5R | 1 + 1 |

### VNH5019A-E CS interface

For each VNH5019A-E use this fixed connection: `CS -> 1.00 kOhm -> GND`; the CS node also goes through `68 kOhm` to the divider node, with `100 kOhm` from that node to GND. Then place `1 kOhm` in series to STM32 `PA0` or `PA1` and `100 nF` from the STM32 pin to GND. Keep the CS traces away from PWM and motor tracks.

The divider ratio is 0.595. With the typical VNH5019 current ratio of about 7030 and the 1.00 kOhm CS load, the STM32 ADC sees approximately **84.6 mV/A**: about 0.42 V at the 5 A design current and about 2.54 V at 30 A. Thus the 3.3 V ADC stays protected even if the bridge is driven far above the normal 5 A operating current. `CS_DIS` is held low through its listed 10 kOhm resistor so current sense remains enabled.

The VNH5019 current-sense ratio has production and temperature tolerance, therefore this circuit is for repeatable measurement, not an absolute current meter. After the first DOOR-8CH board is assembled, measure one known load current, calibrate `CURRENT_MA_PER_ADC_COUNT_NUM` in the STM32 firmware, then set the per-actuator over-current limit to **5 A** in the cabinet configuration.

## Master-only sensor and UART parts

| Purpose | Component and nominal | Quantity for system |
| --- | --- | ---: |
| CAP1188 INT pull-up | 10 kOhm, 1%, 0.125 W to 3.3 V | 5 |
| CAP1188 RESET pull-down | 10 kOhm, 1%, 0.125 W to GND; RESET is active high | 5 |
| CAP1188 supply bypass near connector | 100 nF, 16 V, X7R + 4.7 uF, 10 V, X5R | 5 + 5 |
| CAP1188 field connector | 2-pin, 3.5 mm pitch, SENSOR/GND, one per channel | 40 |
| CAP1188 sensor-line series resistor | 1 kOhm, 0.125 W initial value; provide 0 Ohm tuning option | 40 |
| Reed input pull resistor | 4.7 kOhm, 1%, 0.125 W; fit to 3.3 V for D-M9N or GND for D-M9P | 17 minimum, 18 recommended |
| Reed input series resistor | 1 kOhm, 0.125 W | 17 minimum, 18 recommended |
| Reed input noise filter | 100 nF, 16 V, X7R at the STM32 connector | 17 minimum, 18 recommended |
| UART TX series resistor | 100 Ohm, 0.125 W, one at each end of each link | 12 |
| SLOT_ID low strap | 10 kOhm, 1%, 0.125 W to GND | 7 |

For every reed location fit **one**, not both, 4.7 kOhm pull directions. D-M9N and D-M9P polarity is then selected in the cabinet configuration. Use screened or twisted sensor cable when it leaves the cabinet.

Each CAP1188 channel has its own two-pin edge connector. Connect one twisted-pair
conductor to `SENSOR` and the other to `GND`; the GND conductor is a nearby return
or shield and must not be electrically joined to the isolated touch electrode.
Populate only the connectors needed by the installation, while retaining all eight
channels on every universal board.

## CAN bus and cable entry

| Item | Quantity | Specification |
| --- | ---: | --- |
| CAN connector, 4-pin | 8 | CANH, CANL, CAN_GND, shield/drain. In a five-cabinet daisy chain: one at each endpoint and two at each of three intermediate cabinets. ESP32 is wired internally in the double-door cabinet. |
| CAN termination jumper footprint | 5 | One on every MASTER carrier. Fit 120 Ohm, 0.25 W only at the two physical ends of the complete cable. Buy 5 resistors, populate 2. |
| CAN common-mode choke | 5 | One at each cabinet cable entry, for example a 51 Ohm common-mode impedance class part suitable for CAN. |
| Dual CAN TVS protector | 5 | Automotive CAN-rated dual-line protector, for example SM24CANB class, at each cabinet cable entry. |
| CAN cable | As measured | 120 Ohm twisted pair plus reference ground; use shielded cable in electrically noisy routes. |

The system total is **six CAN transceiver modules**: five in S1 MASTER zones and one beside the ESP32. The selected SN65HVD230 module uses 3.3 V logic directly, matching STM32 and ESP32 GPIO. Its `CANH` and `CANL` pins still require the board-level TVS, common-mode choke and correct two-end termination described above.

## 12 V cabinet power entry and protection

### Low-voltage DC/DC selection

Do **not** use the pictured `CA-1235` / MP1495 mini-module in a permanent cabinet.
Its stated 5 to 15 V input range leaves no practical margin for motor-supply
transients on a nominal 12 V line. It is acceptable only on a clean bench supply
for a short test.

For a preferred long-term DC/DC part, select a fixed 5 V buck module with all
of the following:

- input operating range of 9 to 36 V or wider;
- regulated 5.0 V output, 3 A continuous rating or higher;
- short-circuit and thermal protection;
- screw terminals or locking connectors, rather than loose Dupont wiring.

Install it after the cabinet's reverse-polarity circuit and main fuse. The listed
input TVS and capacitors remain mandatory: a wide-range converter does not remove
the need to suppress motor transients at the 12 V entry. The MP1584 exception
below is permitted only with its stricter listed protection parts.

**Preferred part when available:** `Mean Well RSD-30G-5`, five pieces. Its
specified 9 to 36 V input and 5 V / 6 A output leave ample margin for the actual
low-voltage load while remaining within the protected 12 V cabinet branch. [Manufacturer data sheet](https://www.meanwell.com/Upload/PDF/RSD-30/RSD-30-spec.pdf)

**Compact alternative:** `Pololu D24V50F5`, when its small PCB form factor is
more important than a screw-terminal enclosed converter. It accepts 6 to 38 V,
delivers a typical 5 A continuous at fixed 5 V, and includes reverse-voltage,
over-current, short-circuit and thermal protection. It still requires the same
cabinet TVS, fuse and secure mounting. [Pololu specifications](https://www.pololu.com/product/2851)

**Available selected part:** the pictured `MP1584` 5 V / 3 A mini-module. Buy
seven modules: five installed and two spares. It is acceptable because the actual
5 V load in every cabinet is below 1 A, but it is not a 3 A continuous thermal
design. Select the fixed **5 V** version, solder the wires to its pads, add
strain relief and mount it on an insulated carrier; do not use Dupont jumpers.

The original MP1584 specifies 28 V maximum operating input and 30 V absolute
maximum. Its seller marking of 30 V is therefore not a design target. Use it
only behind the listed `SMBJ16A` TVS and a branch fuse, which keep the protected
logic branch below the operating limit during short motor transients. [MP1584 data sheet](https://www.digikey.com/en/htmldatasheets/production/1785679/0/0/1/mp1584.html)

| Item | Quantity | Specification |
| --- | ---: | --- |
| Main cabinet fuse holder | 5 | DIN-rail or automotive blade type. |
| Main cabinet fuse | 1 x 50 A, 3 x 25 A, 1 x 15 A | Slow-blow or automotive blade. |
| Logic DC/DC branch fuse holder | 5 | One after the reverse-polarity circuit, before the MP1584 input. |
| Logic DC/DC branch fuse | 5 x 1 A | Slow-blow or automotive blade. |
| Per-actuator fuse holder | 22 | One per VNH5019A-E motor supply. |
| Per-actuator fuse | 22 x 7.5 A | Slow-blow or automotive blade. |
| Reverse-polarity MOSFET | 5 | P-channel, >=40 V, low Rds(on), current rating above cabinet peak; IRF4905 class or a proper ideal-diode controller solution. |
| Gate resistor / gate pull-up | 100 Ohm + 100 kOhm, 0.125 W | 5 + 5 |
| Gate-source zener | 12 V, 0.5 W | 5 |
| 12 V transient suppressor | SMBJ16A, 600 W, unidirectional | 5 | Required when using an MP1584 module; its approximate 26 V clamp preserves margin below the converter's 28 V operating maximum. |
| DC/DC input bulk capacitor | 470 uF, **50 V**, low-ESR, >=105 C | 5 |
| DC/DC input ceramic | 1 uF, 50 V, X7R + 100 nF, 50 V, X7R | 5 + 5 |
| DC/DC output bulk capacitor | 220 uF, 10 V, low-ESR | 5 |
| DC/DC output ceramic | 10 uF, 10 V, X5R + 100 nF, 16 V, X7R | 5 + 5 |

The `5 A` current limit and `7.5 A` fuse are based on the measured 2.5 A maximum with a
two-times reserve. Before commissioning, record the short start current at 12 V. If it is
above 7.5 A for long enough to blow the fuse, increase the fuse only after confirming that
the cable, connectors, VNH thermal design and programmed current limit remain protected.

The current 8 A firmware default is a commissioning placeholder. It must be changed to
5 A only after VNH5019 CS calibration is verified on the finished DOOR-8CH board.

## Enclosures, wiring and installation hardware

| Item | Quantity | Notes |
| --- | ---: | --- |
| IP-rated control cabinet | 5 | One per physical object. Choose size after heat and cable-entry layout. |
| DIN rail | 5 sets | For fuses, DC/DC, terminals and power distribution. |
| 12 V distribution terminal blocks | 5 sets | Separate motor positive distribution and star ground point. |
| 2-pin actuator terminal blocks | 22 | **Phoenix Contact MKDS 1,5/ 2-5,08, 1715721**; 5.08 mm pitch, 17.5 A. Search-compatible substitute: KF2EDG 5.08-2P straight, >=10 A, >=1.0 mm2. |
| 4-pin two-channel-slot motor-power terminal blocks | 11 | 5.08 mm pitch; MKDS 1,5/ 4-5,08 or KF2EDG 5.08-4P. Carries separately fused CH1 and CH2 inputs. |
| 3-pin sensor terminals | 14 minimum, 15 recommended | 3.3 V, signal, GND. |
| 8-pin CAP1188 terminals/headers | 4 | 3.3 V, GND, CS, SCK, MISO, MOSI, IRQ, RESET. |
| External UART cable assemblies | 0 | Master-to-slave UART links are internal DOOR-8CH PCB tracks. |
| 4-pin CAN terminal blocks | 8 | CANH, CANL, CAN_GND, shield/drain; IN/OUT at the three intermediate cabinets. |
| Cable glands | As measured | Separate motor, sensor and CAN entries. |
| Motor cable | As measured | Cross-section selected from length and fuse rating. Do not use thin Dupont wire. |
| Ferrules, labels and heat-shrink | As needed | Label every actuator, sensor and CAN address. |
| 40 mm / 60 mm cabinet fan | As thermal test requires | Add when VNH module or DC/DC temperature exceeds its safe limit. |

## Commissioning spares

Buy these in addition to the calculated total:

| Item | Spare quantity |
| --- | ---: |
| STM32F103C8T6 board | 1 |
| VNH5019A-E IC | 4 |
| CAN transceiver | 2 |
| 25LC256 EEPROM | 2 |
| CAP1188 module | 1 |
| 12 V to 5 V DC/DC | 1 |
| Assorted 100 nF / 1 uF / 10 uF capacitors and 1 kOhm / 4.7 kOhm / 10 kOhm resistors | 20% above calculated count |

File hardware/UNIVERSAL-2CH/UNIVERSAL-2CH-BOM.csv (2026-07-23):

Value | References | Footprint | Quantity
100NF_16V | C235 | C_0603_1608Metric | 1
100NF_16V_3V3_IN | C237 | C_0603_1608Metric | 1
100NF_16V_3V3_OUT | C239 | C_0603_1608Metric | 1
100NF_25V_PGOOD_VDD | C270 | C_0603_1608Metric | 1
100NF_50V | C232 | C_0603_1608Metric | 1
100NF_EEPROM | C250 | C_0603_1608Metric | 1
100NF_PGOOD_FILTER | C271 | C_0603_1608Metric | 1
100R INA_SER | R1101,R1201 | R_0603_1608Metric | 2
100R INB_SER | R1102,R1202 | R_0603_1608Metric | 2
100R PWM_SER | R1103,R1203 | R_0603_1608Metric | 2
100nF 50V X7R VCC | C1102,C1202 | C_0603_1608Metric | 2
100nF ADC_FILTER | C1103,C1203 | C_0603_1608Metric | 2
10K ADC_SERIES | R1110,R1210 | R_0603_1608Metric | 2
10K CS_DIS_PULLDOWN | R1108,R1208 | R_0603_1608Metric | 2
10K INA_PULLDOWN | R1104,R1204 | R_0603_1608Metric | 2
10K INB_PULLDOWN | R1105,R1205 | R_0603_1608Metric | 2
10K PWM_PULLDOWN | R1106,R1206 | R_0603_1608Metric | 2
10K_1%_PGOOD_BOTTOM | R271 | R_0603_1608Metric | 1
10K_CAP_IRQ_PULLUP | R210 | R_0603_1608Metric | 1
10K_CAP_RESET_PULLDOWN | R209 | R_0603_1608Metric | 1
10K_EEPROM_CS_PULLUP | R260 | R_0603_1608Metric | 1
10K_EEPROM_HOLD_PULLUP | R262 | R_0603_1608Metric | 1
10K_EEPROM_WP_PULLUP | R261 | R_0603_1608Metric | 1
10K_PGOOD_PULLUP | R272 | R_0603_1608Metric | 1
10UF_10V | C234 | C_1206_3216Metric | 1
10UF_10V_3V3_IN | C236 | C_1206_3216Metric | 1
10UF_10V_3V3_OUT | C238 | C_1206_3216Metric | 1
120R_CAN_TERM_DNP | R240 | R_1206_3216Metric | 1
1A_SLOW_5X20 | F230 | Fuseholder_Clip-5x20mm_Bel_FC-203-22_Lateral_P17.80x5.00mm_D1.17mm_Horizontal | 1
1K 1% CS_LOAD | R1109,R1209 | R_0603_1608Metric | 2
1K_CAP_INPUT | R201,R202,R203 | R_0603_1608Metric | 3
1UF_50V | C231 | C_1206_3216Metric | 1
220UF_10V | C233 | CP_Radial_D8.0mm_P3.50mm | 1
226K_1%_PGOOD_TOP | R270 | R_0603_1608Metric | 1
25LC256_SOIC8_CARRIER_ID | U250 | SOIC-8_3.9x4.9mm_P1.27mm | 1
4700UF_10V_LOW_ESR_S1_HOLDUP | C280 | CP_Radial_D12.5mm_P5.00mm | 1
470UF_50V | C230 | CP_Radial_D10.0mm_P5.00mm | 1
470uF 35V LOW_ESR | C1101,C1201 | CP_Radial_D10.0mm_P5.00mm | 2
47K SLOT_S1_ID0 | R3011 | R_0603_1608Metric | 1
4K7 DIAG_PULLUP | R1107,R1207 | R_0603_1608Metric | 2
ACTUATOR_CH1_4P | J1 | DINKLE_2EHDRC-04P_P5.08mm | 1
ACTUATOR_CH2_4P | J2 | DINKLE_2EHDRC-04P_P5.08mm | 1
AMS1117-3V3 | U230 | SOT-223-3_TabPin2 | 1
BAT54S ADC_CLAMP | D1101,D1201 | SOT-23 | 2
CANH_CANL_GND_SHIELD | J240 | TerminalBlock_Phoenix_PT-1,5-4-3.5-H_1x04_P3.50mm_Horizontal | 1
CAP1188_SPI | CAP1 | CAP1188_Adafruit1602_Module_2x13 | 1
CAP_CS1_GND | J211 | TerminalBlock_Phoenix_PT-1,5-2-3.5-H_1x02_P3.50mm_Horizontal | 1
CAP_CS2_GND | J212 | TerminalBlock_Phoenix_PT-1,5-2-3.5-H_1x02_P3.50mm_Horizontal | 1
CAP_CS3_GND | J213 | TerminalBlock_Phoenix_PT-1,5-2-3.5-H_1x02_P3.50mm_Horizontal | 1
CMC_CAN | L240 | L_CommonModeChoke_Coilcraft_1812CAN | 1
LOGIC_12V_GND | J230 | TerminalBlock_Phoenix_PT-1,5-2-3.5-H_1x02_P3.50mm_Horizontal | 1
M3.2 NPTH, TOP HEATSINK | HS1A,HS1B,HS2A,HS2B | MountingHole_3.2mm_M3 | 4
M3.2_NPTH | H1,H2,H3,H4 | MountingHole_M3_2_NPTH | 4
MP1584_FIXED_5V | DC1 | MP1584_Fixed5V_Module_22.3x17mm | 1
PESD1CAN_CANH | D240 | D_SOD-323 | 1
PESD1CAN_CANL | D241 | D_SOD-323 | 1
REED_A_CLOSED_3V3_SIG_GND | J202 | TerminalBlock_Phoenix_PT-1,5-3-3.5-H_1x03_P3.50mm_Horizontal | 1
REED_A_IN_PLACE_3V3_SIG_GND | J203 | TerminalBlock_Phoenix_PT-1,5-3-3.5-H_1x03_P3.50mm_Horizontal | 1
REED_A_OPEN_3V3_SIG_GND | J201 | TerminalBlock_Phoenix_PT-1,5-3-3.5-H_1x03_P3.50mm_Horizontal | 1
SMBJ16A_TVS | D231 | D_SMB | 1
SN65HVD230_MASTER_CAN | CAN1 | SN65HVD230_Module_14.5x16.1mm_1x06 | 1
SS34_S1_HOLDUP_ISOLATION | D280 | D_SMA | 1
SS54_REVERSE_POLARITY | D230 | D_SMB | 1
STM32F103C8T6_MINI_SLOT_S1 | MOD1 | STM32F103C8T6_Mini_CH340_4x10 | 1
SWD_S1_3V3_DIO_CLK_NRST_GND | J220 | PinHeader_1x05_P2.54mm_Vertical | 1
TLV6700DDCR_POWER_MONITOR | U270 | SOT-23-6 | 1
VNH5019A-E | U1,U2 | ST_MultiPowerSO-30 | 2

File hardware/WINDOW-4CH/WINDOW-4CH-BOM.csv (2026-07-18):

Refs | Value | Footprint | Qty | DNP
C230 | 470UF_50V | CP_Radial_D10.0mm_P5.00mm | 1
C231 | 1UF_50V | C_1206_3216Metric | 1
C232 | 100NF_50V | C_0603_1608Metric | 1
C233 | 220UF_10V | CP_Radial_D8.0mm_P3.50mm | 1
C234 | 10UF_10V | C_1206_3216Metric | 1
C235 | 100NF_16V | C_0603_1608Metric | 1
C236 | 10UF_10V_3V3_IN | C_1206_3216Metric | 1
C237 | 100NF_16V_3V3_IN | C_0603_1608Metric | 1
C238 | 10UF_10V_3V3_OUT | C_1206_3216Metric | 1
C239 | 100NF_16V_3V3_OUT | C_0603_1608Metric | 1
C250 | 100NF_EEPROM | C_0603_1608Metric | 1
C270 | 100NF_25V_PGOOD_VDD | C_0603_1608Metric | 1
C271 | 100NF_PGOOD_FILTER | C_0603_1608Metric | 1
C280 | 4700UF_10V_LOW_ESR_S1_HOLDUP | CP_Radial_D12.5mm_P5.00mm | 1
C1101,C1201,C1301,C1401 | 470uF 35V LOW_ESR | CP_Radial_D10.0mm_P5.00mm | 4
C1102,C1202,C1302,C1402 | 100nF 50V X7R VCC | C_0603_1608Metric | 4
C1103,C1203,C1303,C1403 | 100nF ADC_FILTER | C_0603_1608Metric | 4
CAN1 | SN65HVD230_MASTER_CAN | SN65HVD230_Module_14.5x16.1mm_1x06 | 1
CAP1 | CAP1188_SPI | CAP1188_Adafruit1602_Module_2x13 | 1
D230 | SS54_REVERSE_POLARITY | D_SMB | 1
D231 | SMBJ16A_TVS | D_SMB | 1
D240 | PESD1CAN_CANH | D_SOD-323 | 1
D241 | PESD1CAN_CANL | D_SOD-323 | 1
D280 | SS34_S1_HOLDUP_ISOLATION | D_SMA | 1
D1101,D1201,D1301,D1401 | BAT54S ADC_CLAMP | SOT-23 | 4
DC1 | MP1584_FIXED_5V | MP1584_Fixed5V_Module_22.3x17mm | 1
F230 | 1A_SLOW_5X20 | Fuseholder_Clip-5x20mm_Bel_FC-203-22_Lateral_P17.80x5.00mm_D1.17mm_Horizontal | 1
H1-H4 | M3.2_NPTH | MountingHole_M3_2_NPTH | 4
HS1A?,HS1B?,HS2A?,HS2B?,HS3A?,HS3B?,HS4A?,HS4B? | M3.2 NPTH, TOP HEATSINK | MountingHole_3.2mm_M3 | 8
J1 | FUSED_12V_CH1 | TerminalBlock_Phoenix_MKDS-3-2-5.08_1x02_P5.08mm_Horizontal | 1
J2 | FUSED_12V_CH2 | TerminalBlock_Phoenix_MKDS-3-2-5.08_1x02_P5.08mm_Horizontal | 1
J3 | FUSED_12V_CH3 | TerminalBlock_Phoenix_MKDS-3-2-5.08_1x02_P5.08mm_Horizontal | 1
J4 | FUSED_12V_CH4 | TerminalBlock_Phoenix_MKDS-3-2-5.08_1x02_P5.08mm_Horizontal | 1
J9 | ACTUATOR_CH1 | TerminalBlock_Phoenix_MKDS-3-2-5.08_1x02_P5.08mm_Horizontal | 1
J10 | ACTUATOR_CH2 | TerminalBlock_Phoenix_MKDS-3-2-5.08_1x02_P5.08mm_Horizontal | 1
J11 | ACTUATOR_CH3 | TerminalBlock_Phoenix_MKDS-3-2-5.08_1x02_P5.08mm_Horizontal | 1
J12 | ACTUATOR_CH4 | TerminalBlock_Phoenix_MKDS-3-2-5.08_1x02_P5.08mm_Horizontal | 1
J201 | REED_A_OPEN_3V3_SIG_GND | TerminalBlock_Phoenix_PT-1,5-3-3.5-H_1x03_P3.50mm_Horizontal | 1
J202 | REED_A_CLOSED_3V3_SIG_GND | TerminalBlock_Phoenix_PT-1,5-3-3.5-H_1x03_P3.50mm_Horizontal | 1
J203 | REED_A_IN_PLACE_3V3_SIG_GND | TerminalBlock_Phoenix_PT-1,5-3-3.5-H_1x03_P3.50mm_Horizontal | 1
J211 | CAP_CS1_GND | TerminalBlock_Phoenix_PT-1,5-2-3.5-H_1x02_P3.50mm_Horizontal | 1
J212 | CAP_CS2_GND | TerminalBlock_Phoenix_PT-1,5-2-3.5-H_1x02_P3.50mm_Horizontal | 1
J213 | CAP_CS3_GND | TerminalBlock_Phoenix_PT-1,5-2-3.5-H_1x02_P3.50mm_Horizontal | 1
J214 | CAP_CS4_GND | TerminalBlock_Phoenix_PT-1,5-2-3.5-H_1x02_P3.50mm_Horizontal | 1
J220 | SWD_S1_3V3_DIO_CLK_NRST_GND | PinHeader_1x05_P2.54mm_Vertical | 1
J230 | LOGIC_12V_GND | TerminalBlock_Phoenix_PT-1,5-2-3.5-H_1x02_P3.50mm_Horizontal | 1
J240 | CANH_CANL_GND_SHIELD | TerminalBlock_Phoenix_PT-1,5-4-3.5-H_1x04_P3.50mm_Horizontal | 1
L240 | CMC_CAN | L_CommonModeChoke_Coilcraft_1812CAN | 1
MOD1 | STM32F103C8T6_MINI_SLOT_S1 | STM32F103C8T6_Mini_CH340_4x10 | 1
MOD2 | STM32F103C8T6_MINI_SLOT_S2 | STM32F103C8T6_Mini_CH340_4x10 | 1
R201-R204 | 1K_CAP_INPUT | R_0603_1608Metric | 4
R209 | 10K_CAP_RESET_PULLDOWN | R_0603_1608Metric | 1
R210 | 10K_CAP_IRQ_PULLUP | R_0603_1608Metric | 1
R240 | 120R_CAN_TERM_DNP | R_1206_3216Metric | 1
R250,R251 | 100R_UART_TX | R_0603_1608Metric | 2
R260 | 10K_EEPROM_CS_PULLUP | R_0603_1608Metric | 1
R261 | 10K_EEPROM_WP_PULLUP | R_0603_1608Metric | 1
R262 | 10K_EEPROM_HOLD_PULLUP | R_0603_1608Metric | 1
R270 | 226K_1%_PGOOD_TOP | R_0603_1608Metric | 1
R271 | 10K_1%_PGOOD_BOTTOM | R_0603_1608Metric | 1
R272 | 10K_PGOOD_PULLUP | R_0603_1608Metric | 1
R1101,R1201,R1301,R1401 | 100R INA_SER | R_0603_1608Metric | 4
R1102,R1202,R1302,R1402 | 100R INB_SER | R_0603_1608Metric | 4
R1103,R1203,R1303,R1403 | 100R PWM_SER | R_0603_1608Metric | 4
R1104,R1204,R1304,R1404 | 10K INA_PULLDOWN | R_0603_1608Metric | 4
R1105,R1205,R1305,R1405 | 10K INB_PULLDOWN | R_0603_1608Metric | 4
R1106,R1206,R1306,R1406 | 10K PWM_PULLDOWN | R_0603_1608Metric | 4
R1107,R1207,R1307,R1407 | 4K7 DIAG_PULLUP | R_0603_1608Metric | 4
R1108,R1208,R1308,R1408 | 10K CS_DIS_PULLDOWN | R_0603_1608Metric | 4
R1109,R1209,R1309,R1409 | 1K 1% CS_LOAD | R_0603_1608Metric | 4
R1110,R1210,R1310,R1410 | 10K ADC_SERIES | R_0603_1608Metric | 4
R3011 | 47K SLOT_S1_ID0 | R_0603_1608Metric | 1
R3012 | 47K SLOT_S1_ID1 | R_0603_1608Metric | 1
R3021 | 0R SLOT_S2_ID0 | R_0603_1608Metric | 1
R3022 | 47K SLOT_S2_ID1 | R_0603_1608Metric | 1
U1-U4 | VNH5019A-E | ST_MultiPowerSO-30 | 4
U230 | AMS1117-3V3 | SOT-223-3_TabPin2 | 1
U250 | 25LC256_SOIC8_CARRIER_ID | SOIC-8_3.9x4.9mm_P1.27mm | 1
U270 | TLV6700DDCR_POWER_MONITOR | SOT-23-6 | 1

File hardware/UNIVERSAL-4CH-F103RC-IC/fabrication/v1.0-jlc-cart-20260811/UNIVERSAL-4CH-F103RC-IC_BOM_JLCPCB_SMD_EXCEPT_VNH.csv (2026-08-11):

Comment | Designator | Footprint | LCSC Part #
0R 0603; UNI-ROYAL 0603WAF0000T5E | R2301 | R_0603_1608Metric | C21189
100R 1% 0603; UNI-ROYAL 0603WAF1000T5E | R1101,R1102,R1103,R1201,R1202,R1203,R1301,R1302,R1303,R1401,R1402,R1403 | R_0603_1608Metric | C22775
100nF 50V X7R 0603; YAGEO CC0603KRX7R9BB104 | C1102,C1103,C1202,C1203,C1302,C1303,C1402,C1403,C232,C235,C237,C239,C250,C270,C271,C3003,C3004,C3005,C3006,C3009,C340 | C_0603_1608Metric | C14663
10K 1% 0603; UNI-ROYAL 0603WAF1002T5E | R1104,R1105,R1106,R1108,R1110,R1204,R1205,R1206,R1208,R1210,R1304,R1305,R1306,R1308,R1310,R1404,R1405,R1406,R1408,R1410,R209,R210,R260,R261,R262,R271,R272,R3001,R3002,R3003 | R_0603_1608Metric | C25804
10nF 50V X7R 0603 | C3008 | C_0603_1608Metric | C57112
10uF 25V X7R 1206; YAGEO CC1206KKX7R8BB106 | C234,C236,C238 | C_1206_3216Metric | C70462
18pF 50V C0G 0603 | C3001,C3002 | C_0603_1608Metric | C1647
1K 1% 0603; UNI-ROYAL 0603WAF1001T5E | R1109,R1209,R1309,R1409,R201,R202,R203 | R_0603_1608Metric | C21190
1uF 50V X7R 0805; Samsung CL21B105KBFNNNE | C3007,C341 | C_0805_2012Metric | C28323
1uF 50V X7R 1206; CCTC TCC1206X7R105M500FT | C231 | C_1206_3216Metric | C5448921
226K 1% 0603; FH RS-03K2263FT | R270 | R_0603_1608Metric | C321793
25LC256-I/SN SPI EEPROM SOIC-8 | U250 | SOIC-8_3.9x4.9mm_P1.27mm | C84670
4.7K 1% 0603; UNI-ROYAL 0603WAF4701T5E | R1107,R1207,R1307,R1407,R290,R291,R292 | R_0603_1608Metric | C23162
ACT45B-101-2P-TL003 CAN common-mode choke | L240 | L_CommonModeChoke_Coilcraft_1812CAN | C88056
AMS1117-3.3 SOT-223 | U230 | SOT-223-3_TabPin2 | C6186
BAT54S dual Schottky SOT-23; Nexperia BAT54S,215 | D1101,D1201,D1301,D1401 | SOT-23 | C47546
CAP1188-1-CP-TR capacitive touch controller | CAP1 | QFN-24-1EP_4x4mm_P0.5mm_EP2.7x2.7mm | C2652057
ESD24VD3B bidirectional CAN ESD SOD-323 | D240,D241 | D_SOD-323 | C484324
SMBJ16A 600W unidirectional SMB; LGE SMBJ16A | D231 | D_SMB | C713715
SS34 3A 40V SMA Schottky; MDD SS34 | D280 | D_SMA | C8678
SS54 5A 40V SMB; LGE SS54 | D230 | D_SMB | C432139
STM32F103RCT6 LQFP-64 | U300 | LQFP-64_10x10mm_P0.5mm | C8323
TLV6700DDCR dual comparator SOT-23-6 | U270 | SOT-23-6 | C2868382
X32258MOB4SI 8MHz 12pF SMD3225-4P | Y300 | Crystal_SMD_3225-4Pin_3.2x2.5mm | C2682775

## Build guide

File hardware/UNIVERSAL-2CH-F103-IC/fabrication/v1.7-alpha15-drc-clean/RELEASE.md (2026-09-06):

# Two-channel fabrication revision v1.7

Generated 2026-09-06 for the direct-IC STM32F103C8T6 board and alpha15 firmware.
Older releases are retained for history, not for this revised board.

## Digital checks completed

- KiCad 10: zero errors, zero warnings, zero unconnected pads.
- Existing rule severities and exclusions were not changed.
- Conflicting silkscreen labels relocated; no component positions changed.
- Zone minimum feature width is 0.8 mm; zones refilled to remove copper slivers.
- All 106 footprints, both motor track sets and MCU/connector pad assignments
  checked against the previous electrical repair. No new pin changes.
- Direct-IC firmware/power-net audit passes, including the protected monitor
  supply and CAP1188 decoupling.
- Both copper layers, both mask layers, silkscreens, outline and separate
  plated/nonplated drills exported together from the current PCB.
- BOM/CPL regenerated: 75 SMD placements, 3 top and 72 bottom, excluding VNH.
  C340 is now top-side. Do not use an older CPL.

## Required manual assembly

Three insulated wires are still part of this design:

1. C280 positive to J280B.
2. TP290 to JP290 (J220.6).
3. D230 pad 1 (cathode, protected supply) to C270 pad 1.

They connect intentionally separate net names and therefore are not counted
as unrouted tracks by DRC. Zero unconnected pads does not remove these wires.

## Manufacturing versus operation

The archive is current and passes the listed digital fabrication checks.
No physical board has been tested in this revision. Initial current calibration,
power-fail hold-up timing, loaded motor temperature and obstruction-stop testing
must be performed on an assembled prototype; these cannot be validated by DRC.

BOM stock and JLCPCB model orientation have not been checked in a live new order.
CPL uses the existing package corrections; validate pin 1/polarity in the
manufacturer's assembly preview before submitting a populated-board order.
The preview PNGs are KiCad views, not evidence of JLCPCB placement approval.

No order has been created or paid for by this release operation.

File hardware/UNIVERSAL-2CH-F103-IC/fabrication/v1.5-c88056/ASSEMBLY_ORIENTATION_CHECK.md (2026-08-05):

# Assembly orientation check

Release: `v1.5-c88056`

The bottom-side JLCPCB placement preview was checked against pad 1, cathode,
and footprint markings on the KiCad PCB.

## JLCPCB SMD assembly

| References | Check |
| --- | --- |
| CAP1 | Pin 1 marker matches QFN pad 1 |
| U300 | Pin 1 marker matches LQFP pad 1 |
| U250 | Pin 1 marker matches SOIC pad 1 |
| U270 | Pin 1 marker matches SOT-23-6 pad 1 |
| U230 | Pin 1 marker matches SOT-223 pad 1 |
| D1101, D1201 | Pin 1 marker matches BAT54S pad 1 |
| D230 | Cathode matches pad 1 and `LOGIC_12V_PROTECTED` |
| D231 | Cathode matches pad 1 and the PCB cathode marking |
| D280 | Cathode matches pad 1 and the PCB cathode marking |
| D240, D241 | Bidirectional ESD parts; landing and rotation checked |
| Y300 | Pin 1 marker matches crystal pad 1 |
| L240 | TDK ACT45B-101-2P-TL003 (`C88056`); CPL pin 1 matches footprint pad 1 |

All non-polarized resistors and ceramic capacitors were checked for landing,
centering, board-edge clearance, and overlap.

## Manual assembly

The following parts are not included in the JLCPCB SMD placement and must be
installed using PCB silkscreen and pad markings:

- `U1`, `U2`: VNH5019A-E pin 1 and exposed power pads.
- `C1101`, `C1201`, `C230`, `C233`, `C280`: electrolytic capacitor polarity.
- `D240`, `D241`, or any other DNP SMD part if fitted manually.
- `CAN1`, `DC1`: module header orientation and supply polarity.
- All pluggable terminal blocks: wire order must follow the silkscreen labels.

KiCad DRC result: 0 violations, 0 unconnected pads, 0 footprint errors.

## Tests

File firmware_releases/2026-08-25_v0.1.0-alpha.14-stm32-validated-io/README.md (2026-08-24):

# STM32 Universal Actuator Node v0.1.0-alpha.14

Target: STM32F103C8T6, two VNH5019A-E actuator channels.

Changes from alpha.12:

- limits CAN receive processing to 20 frames per loop pass;
- limits each UART receive link to 10 frames per loop pass;
- rejects unsupported command values before they affect the heartbeat;
- validates fault and object-type values received from other controllers;
- writes the internal configuration with CRC, read-back comparison and up to
  three attempts;
- stops motion and latches `ConfigStorage` when configuration storage cannot be
  verified;
- keeps the existing EEPROM layout and alpha.12 calibration data compatible.

Build target:

`STMicroelectronics:stm32:GenF1:pnum=GENERIC_F103C8TX,xserial=none,usb=none,opt=oslto,dbg=none,rtlib=nano`

Bench-test with current-limited motor power before connecting mechanics.

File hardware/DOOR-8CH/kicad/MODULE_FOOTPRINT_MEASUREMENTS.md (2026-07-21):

# Module measurements required before fabrication

The following sockets are already based on the pictured 2.54 mm module
headers: two SN65HVD230 modules and the 2x4 CC1101 module. Verify this with a
physical module before ordering boards.

The photographed module dimensions currently used by the board are:

| Module | Needed measurements | Why |
| --- | --- | --- |
| STM32F103C8T6 mini | confirm 20.32 mm between the outer rows, 2.54 mm within each pair, and the 32 x 22.86 mm outline | the photographed board has four 1x10 rows, not two 1x15 rows; a single 40-pin footprint is used |
| YD ESP32-S3 N16R8, dual USB-C | 22 pins per side, 2.54 mm pitch, 25.40 mm row spacing | photo-matched footprint; still verify with a 1:1 print |
| CAP1188 breakout | left/right header row spacing, pin count, full outline, mounting-hole positions | the supplied photo shows a vendor-specific breakout with more than the minimum SPI pins |

Measure with a ruler or caliper and photograph each module next to it. Values
to 0.5 mm are sufficient for the first board outline; header pitch should be
confirmed as 2.54 mm.

No fabrication output is generated until these measurements are entered and a
1:1 print is checked against the real modules.

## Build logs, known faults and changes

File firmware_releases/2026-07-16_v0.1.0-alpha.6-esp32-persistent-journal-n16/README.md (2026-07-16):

# ESP32-S3 coordinator v0.1.0-alpha.6 N16

Changes:

- Receives cabinet power-recovery event frames over CAN.
- Stores the 48-entry web event journal as a persistent NVS ring.
- Preserves journal entries across ESP32 power cycles and restarts.
- Persists journal clearing requested from the web interface.

Hardware target: ESP32-S3 with 16 MB DIO Flash, PSRAM disabled and the 3 MB
application partition. Use the merged image at address `0x00000000` for a full
first flash.

Build result:

- Flash: 1022033 bytes, 32 percent of the 3 MB application partition.
- RAM: 57936 bytes, 17 percent of 320 KB.

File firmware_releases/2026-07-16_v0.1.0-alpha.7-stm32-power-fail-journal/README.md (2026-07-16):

# STM32 Universal Actuator Node v0.1.0-alpha.7

Changes:

- Detects a falling `POWER_GOOD` signal on MASTER PC13.
- Stops local outputs and sends STOP to populated SLAVE slots.
- Stores one CRC-protected outage record in the held carrier EEPROM.
- Reports `PowerRecovered` over CAN after restart and then acknowledges the
  saved record.

Build result:

- Flash: 23832 bytes, 36 percent of STM32F103C8T6 64 KB target.
- RAM: 3508 bytes, 17 percent of 20 KB target.

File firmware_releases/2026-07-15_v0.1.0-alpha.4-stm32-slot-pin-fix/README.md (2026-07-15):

# STM32 universal node v0.1.0-alpha.4

This release corrects hardware slot identification for the photographed
MuLuoxing STM32F103C8T6 mini CH340 module.

- Slot ID0 moved from unavailable PC14 to exposed PB2.
- Slot ID1 moved from unavailable PC15 to exposed PA7.
- PA7 is sampled before SPI starts and is reused as CAP1188 MOSI only by S1.
- The same binary remains valid in every S1-S4 socket.

Required DOOR-8CH carrier straps:

| Slot | PB2 | PA7 | Role |
| --- | --- | --- | --- |
| S1 | pull-up | pull-up | MASTER |
| S2 | GND | pull-up | SLAVE 1 |
| S3 | pull-up | GND | SLAVE 2 |
| S4 | GND | GND | SLAVE 3 |

Do not use this build with the abandoned PC14/PC15 strap proposal.

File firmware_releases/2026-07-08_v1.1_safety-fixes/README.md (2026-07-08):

# Версия 2026-07-08 v1.1 safety-fixes

Эта папка содержит сохраненную версию прошивок ESP32 и RP2040 после исправлений надежности.

## Что входит

- `ESP32_CC1101_RS485_Master_v1.1.ino` - исходник ESP32.
- `ESP32_CC1101_RS485_Master_v1.1.bin` - основной бинарный файл ESP32 для OTA/прошивки приложения.
- `ESP32_CC1101_RS485_Master_v1.1.merged.bin` - полный образ ESP32.
- `RP2040_RS485_Window_Node_4A_v1.1.ino` - исходник RP2040.
- `RP2040_RS485_Window_Node_4A_v1.1.uf2` - прошивка RP2040 для копирования на диск платы.

## Изменения

- Добавлена версия прошивки `v1.1-safety-fixes` в статусы ESP32 и RP2040.
- ESP32: защищен RF-буфер пульта через `portMUX_TYPE`.
- ESP32: добавлена безопасная инициализация записей кнопок пультов.
- ESP32: усилена обработка импорта настроек, добавлена защита от слишком большого backup-файла.
- RP2040: добавлен watchdog.
- RP2040: I2C снижен до 100 kHz для повышения устойчивости.
- RP2040: добавлена повторная инициализация INA219.
- RP2040: CAP1188 проверяется до включения реле.
- RP2040: повторная команда уже достигнутого положения не запускает актуаторы.
- RP2040: JSON-статус экранирует строки.
- RP2040: буфер flash-сохранения перенес из стека в static-память.
- RP2040: watchdog обновляется перед и после записи настроек во flash.

## Сборка

ESP32:

```powershell
arduino-cli compile --fqbn esp32:esp32:esp32s3 --export-binaries ArduinoIDE/ESP32_CC1101_RS485_Master
```

RP2040:

```powershell
arduino-cli compile --fqbn arduino:mbed_rp2040:pico --export-binaries ArduinoIDE/RP2040_RS485_Window_Node_4A
```

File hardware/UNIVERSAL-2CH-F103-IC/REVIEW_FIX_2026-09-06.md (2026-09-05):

# Two-channel review corrections, 2026-09-06

## Status

The current KiCad PCB and STM32 alpha.15 source contain the focused review
corrections below. This is an engineering revision, not approval of the old
manufacturing archives or the JLCPCB cart. No order was placed or changed.

## PCB

- U270.5, C270.1 and R270.1 now share POWER_MONITOR_12V. The old feed from
  LOGIC_12V_FUSED was disconnected and its unused branch removed.
- Install a wire from D230.1 (cathode, LOGIC_12V_PROTECTED) to C270.1 to supply
  this branch after the reverse-polarity diode. Both ends are existing SMD
  pads. The divider now measures the protected rail, so the input-referred
  trip voltage additionally includes the forward drop of D230.
- C340 (100 nF) moved to F.Cu at (83.5, 54.8) mm and connects to S1_3V3,
  after the existing TP290-to-JP290 wire. Its ground connection uses a local
  via. C341 remains on the MCU supply branch.
- Existing C280+ -> J280B and TP290 -> JP290 (J220.6) wires remain mandatory.
  The total is THREE wires. Check continuity and polarity before powering.
- Connector placement, drill sizes, STM32 mappings, VNH footprints and motor
  tracks were not changed. The automatic comparison checked all 106 footprints.

## Firmware

- Time is refreshed after command processing, before protection uses it.
  This prevents unsigned underflow when direction dead-time advances millis().
- Movement completion only runs in Moving or Calibrating state and preserves
  the completed direction before clearing the active command.
- Before reporting successful completion, the master requires the target reed
  input; a double door requires both corresponding reed inputs. Missing
  confirmation raises NoCurrent and skips calibration application.
- A configured CAP1188 is required for windows as well as doors. A zero sensor
  mask explicitly disables this requirement.
- Before motion, CAP identity and enabled/interrupt masks are read back. An
  already-touched edge blocks closing before PWM starts.
- CAP identity and masks are checked every 250 ms during normal polling.
  Failure raises Cap1188Offline; ClearFault can reinitialize the device.
- EEPROM structure and protocol numbers are unchanged. Version is alpha.15.

## Verification

- Arduino STM32 Generic F103C8 build: 24,792 bytes Flash, 3,508 bytes static RAM.
- KiCad 10 DRC: 0 errors, 0 unconnected pads, 52 warnings. The warnings are
  48 silkscreen issues and 4 copper-sliver warnings. They were not suppressed
  to obtain this result.
- tools/verify_2ch_review_fix.py passed: all footprint/pad mappings compared
  against 7606dc24930b113c63ee8d6200549ff06856821e, with only the four intended
  net changes and C340 relocation allowed. Motor track sets match the baseline.
- Firmware was compiled and reviewed; motion/fault behavior has not been run
  on physical hardware. No thermal, EMC, force or contact-safety test was done.

## Remaining limits

- A group reed confirms the window position, not the position of every motor.
  Current disappearance alone cannot distinguish every individual cable fault
  from an internal limit switch. Independent actuator feedback is required
  for that distinction.
- CAP health polling is not an independent hardware safety circuit. Blocking
  command handling means the configured polling periods are not a guaranteed
  worst-case reaction time.
- Current conversion still needs per-channel bench calibration. Hold-up time
  and actual power-fail EEPROM writes also require power-interruption testing.
- Existing Gerbers/CPL files predate this change. C340 changed side and supply
  routing changed; do not reuse those files for this PCB revision.
- The 52 DRC warnings and mechanical/thermal checks remain before a production
  release. The focused correction does not certify the entire design.

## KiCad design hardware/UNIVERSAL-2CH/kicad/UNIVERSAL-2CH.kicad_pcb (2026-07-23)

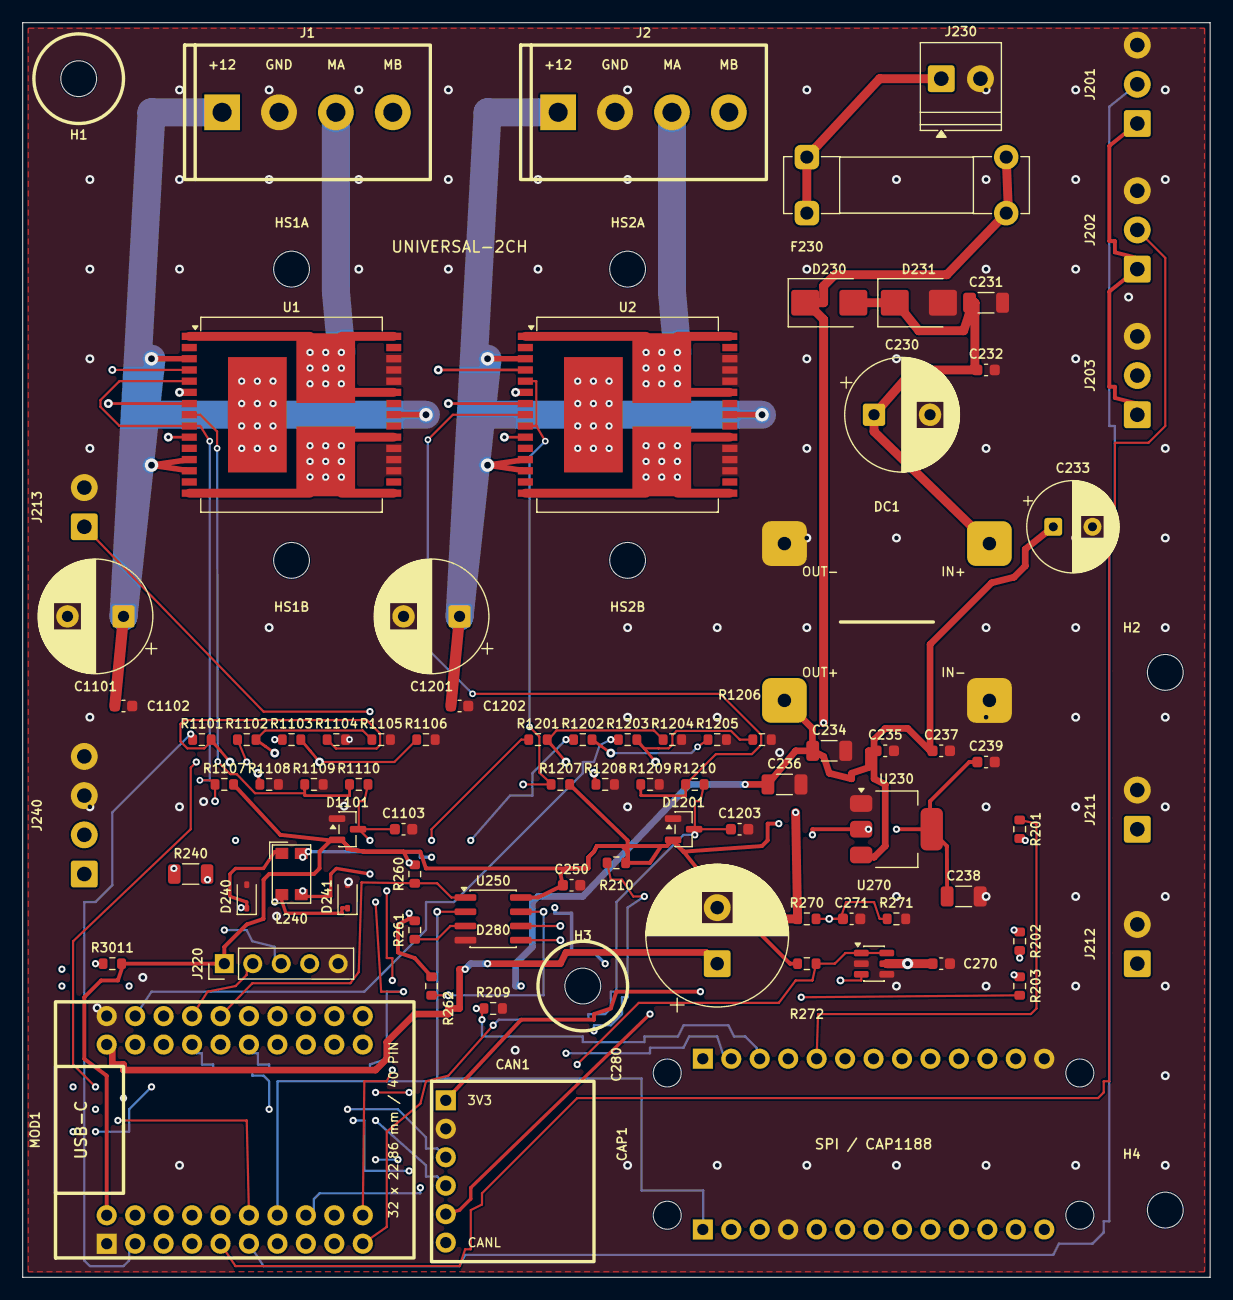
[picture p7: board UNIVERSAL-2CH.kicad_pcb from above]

Board: 4 copper layers, 106.0 x 112.0 mm, 90 parts (1 on the bottom side), 64 nets.

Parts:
C230: 470UF_50V; CP_Radial_D10.0mm_P5.00mm
C231: 1UF_50V; C_1206_3216Metric
C232: 100NF_50V; C_0603_1608Metric
C233: 220UF_10V; CP_Radial_D8.0mm_P3.50mm
C234: 10UF_10V; C_1206_3216Metric
C235: 100NF_16V; C_0603_1608Metric
C236: 10UF_10V_3V3_IN; C_1206_3216Metric
C237: 100NF_16V_3V3_IN; C_0603_1608Metric
C238: 10UF_10V_3V3_OUT; C_1206_3216Metric
C239: 100NF_16V_3V3_OUT; C_0603_1608Metric
C250: 100NF_EEPROM; C_0603_1608Metric
C270: 100NF_25V_PGOOD_VDD; C_0603_1608Metric
C271: 100NF_PGOOD_FILTER; C_0603_1608Metric
C280: 4700UF_10V_LOW_ESR_S1_HOLDUP; CP_Radial_D12.5mm_P5.00mm
C1101, C1201: 470uF 35V LOW_ESR; CP_Radial_D10.0mm_P5.00mm
C1102, C1202: 100nF 50V X7R VCC; C_0603_1608Metric
C1103, C1203: 100nF ADC_FILTER; C_0603_1608Metric
CAN1: SN65HVD230_MASTER_CAN; SN65HVD230_Module_14.5x16.1mm_1x06
CAP1: CAP1188_SPI; CAP1188_Adafruit1602_Module_2x13
D230: SS54_REVERSE_POLARITY; D_SMB
D231: SMBJ16A_TVS; D_SMB
D240: PESD1CAN_CANH; D_SOD-323
D241: PESD1CAN_CANL; D_SOD-323
D280: SS34_S1_HOLDUP_ISOLATION; D_SMA
D1101, D1201: BAT54S ADC_CLAMP; SOT-23
DC1: MP1584_FIXED_5V; MP1584_Fixed5V_Module_22.3x17mm
F230: 1A_SLOW_5X20; Fuseholder_Clip-5x20mm_Bel_FC-203-22_Lateral_P17.80x5.00mm_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
H1, H2, H3, H4: M3.2_NPTH; MountingHole_M3_2_NPTH
HS1A, HS1B, HS2A, HS2B: M3.2 NPTH, TOP HEATSINK; MountingHole_3.2mm_M3
J1: ACTUATOR_CH1_4P; DINKLE_2EHDRC-04P_P5.08mm
J2: ACTUATOR_CH2_4P; DINKLE_2EHDRC-04P_P5.08mm
J201: REED_A_OPEN_3V3_SIG_GND; TerminalBlock_Phoenix_PT-1,5-3-3.5-H_1x03_P3.50mm_Horizontal
J202: REED_A_CLOSED_3V3_SIG_GND; TerminalBlock_Phoenix_PT-1,5-3-3.5-H_1x03_P3.50mm_Horizontal
J203: REED_A_IN_PLACE_3V3_SIG_GND; TerminalBlock_Phoenix_PT-1,5-3-3.5-H_1x03_P3.50mm_Horizontal
J211: CAP_CS1_GND; TerminalBlock_Phoenix_PT-1,5-2-3.5-H_1x02_P3.50mm_Horizontal
J212: CAP_CS2_GND; TerminalBlock_Phoenix_PT-1,5-2-3.5-H_1x02_P3.50mm_Horizontal
J213: CAP_CS3_GND; TerminalBlock_Phoenix_PT-1,5-2-3.5-H_1x02_P3.50mm_Horizontal
J220: SWD_S1_3V3_DIO_CLK_NRST_GND; PinHeader_1x05_P2.54mm_Vertical
J230: LOGIC_12V_GND; TerminalBlock_Phoenix_PT-1,5-2-3.5-H_1x02_P3.50mm_Horizontal
J240: CANH_CANL_GND_SHIELD; TerminalBlock_Phoenix_PT-1,5-4-3.5-H_1x04_P3.50mm_Horizontal
L240: CMC_CAN; L_CommonModeChoke_Coilcraft_1812CAN
MOD1: STM32F103C8T6_MINI_SLOT_S1; STM32F103C8T6_Mini_CH340_4x10
R201, R202, R203: 1K_CAP_INPUT; R_0603_1608Metric
R209: 10K_CAP_RESET_PULLDOWN; R_0603_1608Metric
R210: 10K_CAP_IRQ_PULLUP; R_0603_1608Metric
R240: 120R_CAN_TERM_DNP; R_1206_3216Metric
R260: 10K_EEPROM_CS_PULLUP; R_0603_1608Metric
R261: 10K_EEPROM_WP_PULLUP; R_0603_1608Metric
R262: 10K_EEPROM_HOLD_PULLUP; R_0603_1608Metric
R270: 226K_1%_PGOOD_TOP; R_0603_1608Metric
R271: 10K_1%_PGOOD_BOTTOM; R_0603_1608Metric
R272: 10K_PGOOD_PULLUP; R_0603_1608Metric
R1101, R1201: 100R INA_SER; R_0603_1608Metric
R1102, R1202: 100R INB_SER; R_0603_1608Metric
R1103, R1203: 100R PWM_SER; R_0603_1608Metric
R1104, R1204: 10K INA_PULLDOWN; R_0603_1608Metric
R1105, R1205: 10K INB_PULLDOWN; R_0603_1608Metric
R1106, R1206: 10K PWM_PULLDOWN; R_0603_1608Metric
R1107, R1207: 4K7 DIAG_PULLUP; R_0603_1608Metric
R1108, R1208: 10K CS_DIS_PULLDOWN; R_0603_1608Metric
R1109, R1209: 1K 1% CS_LOAD; R_0603_1608Metric
R1110, R1210: 10K ADC_SERIES; R_0603_1608Metric
R3011: 47K SLOT_S1_ID0; R_0603_1608Metric
U1, U2: VNH5019A-E; ST_MultiPowerSO-30
U230: AMS1117-3V3; SOT-223-3_TabPin2
U250: 25LC256_SOIC8_CARRIER_ID; SOIC-8_3.9x4.9mm_P1.27mm
U270: TLV6700DDCR_POWER_MONITOR; SOT-23-6

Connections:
CANH_BUS: CAN1.5, L240.4, R240.1
CANH_ENTRY: D240.1, J240.1, L240.1
CANL_BUS: CAN1.6, L240.3, R240.2
CANL_ENTRY: D241.1, J240.2, L240.2
CAP_C1_FIELD: J211.1, R201.2
CAP_C1_RAW: CAP1.18, R201.1
CAP_C2_FIELD: J212.1, R202.2
CAP_C2_RAW: CAP1.19, R202.1
CAP_C3_FIELD: J213.1, R203.2
CAP_C3_RAW: CAP1.20, R203.1
CAP_CS: CAP1.15, MOD1.18
CAP_IRQ: MOD1.13, R210.1
CAP_MISO: CAP1.1, MOD1.17, U250.2
CAP_MOSI: CAP1.14, MOD1.7, U250.5
CAP_RESET: CAP1.16, MOD1.29, R209.1
CAP_SCK: CAP1.2, MOD1.8, U250.6
CH1_CS_DIS: R1108.1, U1.6
CH1_CS_RAW: R1109.1, R1110.1, U1.8
CH1_CURRENT_ADC: C1103.1, D1101.3, MOD1.20, R1110.2
CH1_DIAG: MOD1.27, R1107.1, U1.5, U1.9
CH1_INA: R1101.2, R1104.1, U1.4
CH1_INA_MCU: MOD1.2, R1101.1
CH1_INB: R1102.2, R1105.1, U1.10
CH1_INB_MCU: MOD1.12, R1102.1
CH1_OUTA: J1.3, U1.1, U1.25, U1.30, U1.33
CH1_OUTB: J1.4, U1.15, U1.16, U1.21, U1.32
CH1_PWM: R1103.2, R1106.1, U1.7
CH1_PWM_MCU: MOD1.22, R1103.1
CH2_CS_DIS: R1208.1, U2.6
CH2_CS_RAW: R1209.1, R1210.1, U2.8
CH2_CURRENT_ADC: C1203.1, D1201.3, MOD1.10, R1210.2
CH2_DIAG: MOD1.3, R1207.1, U2.5, U2.9
CH2_INA: R1201.2, R1204.1, U2.4
CH2_INA_MCU: MOD1.26, R1201.1
CH2_INB: R1202.2, R1205.1, U2.10
CH2_INB_MCU: MOD1.36, R1202.1
CH2_OUTA: J2.3, U2.1, U2.25, U2.30, U2.33
CH2_OUTB: J2.4, U2.15, U2.16, U2.21, U2.32
CH2_PWM: R1203.2, R1206.1, U2.7
CH2_PWM_MCU: MOD1.32, R1203.1
EEPROM_CS: MOD1.35, R260.1, U250.1
EEPROM_HOLD: R262.1, U250.7
EEPROM_WP: R261.1, U250.3
FUSED_12V_CH1: C1101.1, C1102.1, J1.1, U1.3, U1.12, U1.13, U1.23, U1.31
FUSED_12V_CH2: C1201.1, C1202.1, J2.1, U2.3, U2.12, U2.13, U2.23, U2.31
GND: C230.2, C231.2, C232.2, C233.2, C234.2, C235.2, C236.2, C237.2, C238.2, C239.2, C250.2, C270.2, C271.2, C280.2, C1101.2, C1102.2, C1103.2, C1201.2, C1202.2, C1203.2, CAN1.2, CAP1.4, CAP1.26, D231.2, D240.2, D241.2, D1101.1, D1201.1, DC1.2, DC1.4, J1.2, J2.2, J201.3, J202.3, J203.3, J211.2, J212.2, J213.2, J220.5, J230.2, J240.3, J240.4, MOD1.1, MOD1.31, R209.2, R271.2, R1104.2, R1105.2, R1106.2, R1108.2, R1109.2, R1204.2, R1205.2, R1206.2, R1208.2, R1209.2, U1.18, U1.19, U1.20, U1.26, U1.27, U1.28, U2.18, U2.19, U2.20, U2.26, U2.27, U2.28, U230.1, U250.4, U270.2, U270.4
LOGIC_3V3: C238.1, C239.1, CAN1.1, U230.2
LOGIC_5V: C233.1, C234.1, C235.1, C236.1, C237.1, CAP1.3, D280.2, DC1.3, U230.3
LOGIC_12V_FUSED: C270.1, D230.1, F230.2, R270.1, U270.5
LOGIC_12V_IN: F230.1, J230.1
LOGIC_12V_PROTECTED: C230.1, C231.1, C232.1, D230.2, D231.1, DC1.1
PGOOD_SENSE: C271.1, R270.2, R271.1, U270.3
POWER_GOOD: MOD1.30, R272.2, U270.1, U270.6
REED_A_CLOSED: J202.2, MOD1.5
REED_A_IN_PLACE: J203.2, MOD1.38
REED_A_OPEN: J201.2, MOD1.6
S1_3V3: C250.1, D1101.2, D1201.2, J201.1, J202.1, J203.1, J220.1, MOD1.11, R210.2, R260.2, R261.2, R262.2, R272.1, R1107.2, R1207.2, R3011.2, U250.8
S1_5V_HOLD: C280.1, D280.1, MOD1.21
S1_CAN_RX: CAN1.4, MOD1.33
S1_CAN_TX: CAN1.3, MOD1.24
S1_NRST: J220.4, MOD1.16
S1_SLOT_ID0: MOD1.15, R3011.1
S1_SWCLK: J220.3, MOD1.25
S1_SWDIO: J220.2, MOD1.34

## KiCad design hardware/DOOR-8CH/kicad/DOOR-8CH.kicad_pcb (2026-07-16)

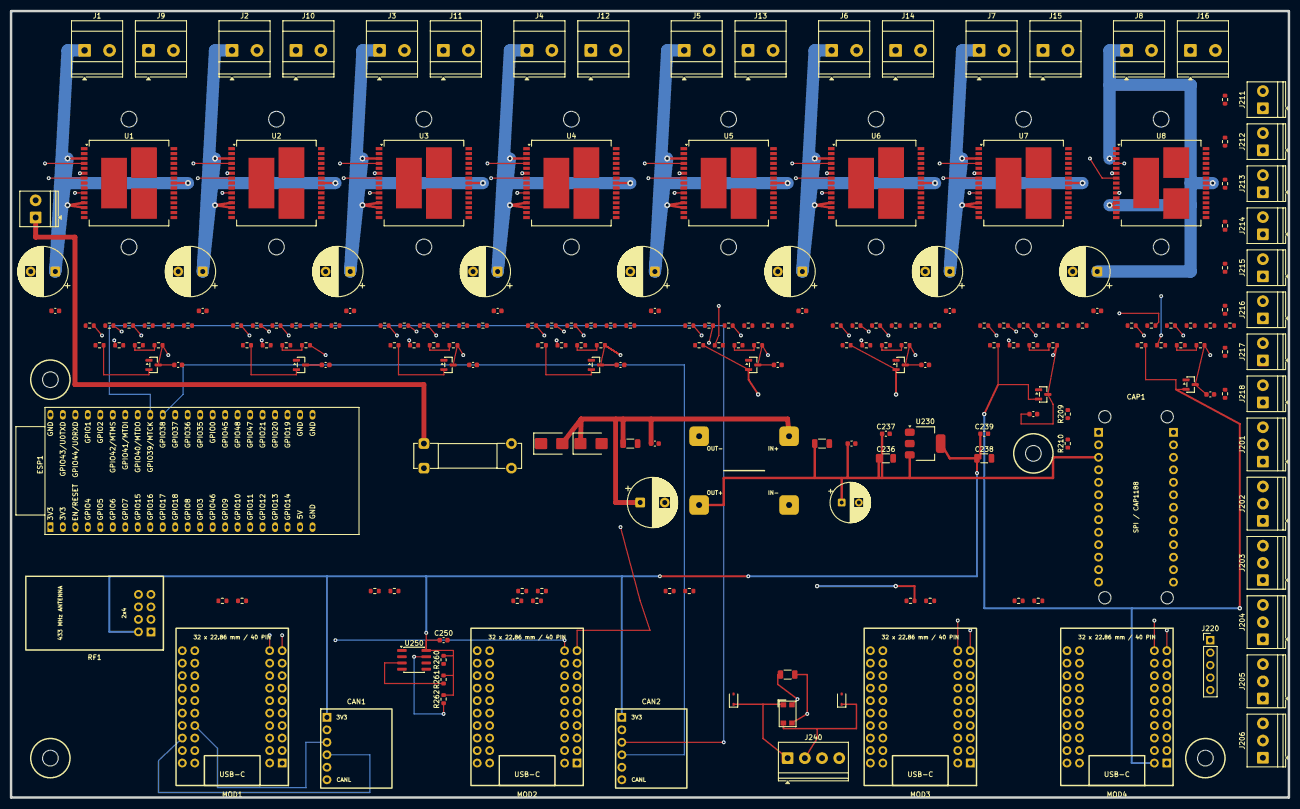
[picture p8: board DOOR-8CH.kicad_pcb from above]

Board: 4 copper layers, 260.0 x 160.0 mm, 230 parts (0 on the bottom side), 181 nets.

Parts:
C230: 470UF_50V; CP_Radial_D10.0mm_P5.00mm
C231: 1UF_50V; C_1206_3216Metric
C232: 100NF_50V; C_0603_1608Metric
C233: 220UF_10V; CP_Radial_D8.0mm_P3.50mm
C234: 10UF_10V; C_1206_3216Metric
C235: 100NF_16V; C_0603_1608Metric
C236: 10UF_10V_3V3_IN; C_1206_3216Metric
C237: 100NF_16V_3V3_IN; C_0603_1608Metric
C238: 10UF_10V_3V3_OUT; C_1206_3216Metric
C239: 100NF_16V_3V3_OUT; C_0603_1608Metric
C250: 100NF_EEPROM; C_0603_1608Metric
C1101, C1201, C1301, C1401, C1501, C1601, C1701, C1801: 470uF 35V LOW_ESR; CP_Radial_D10.0mm_P5.00mm
C1102, C1202, C1302, C1402, C1502, C1602, C1702, C1802: 100nF 50V X7R VCC; C_0603_1608Metric
C1103, C1203, C1303, C1403, C1503, C1603, C1703, C1803: 100nF ADC_FILTER; C_0603_1608Metric
CAN1: SN65HVD230_MASTER_CAN; SN65HVD230_Module_14.5x16.1mm_1x06
CAN2: SN65HVD230_ESP_CAN_OPTION; SN65HVD230_Module_14.5x16.1mm_1x06
CAP1: CAP1188_SPI; CAP1188_Adafruit1602_Module_2x13
D230: SS54_REVERSE_POLARITY; D_SMB
D231: SMBJ16A_TVS; D_SMB
D240: PESD1CAN_CANH; D_SOD-323
D241: PESD1CAN_CANL; D_SOD-323
D1101, D1201, D1301, D1401, D1501, D1601, D1701, D1801: BAT54S ADC_CLAMP; SOT-23
DC1: MP1584_FIXED_5V; MP1584_Fixed5V_Module_22.3x17mm
ESP1: ESP32_S3_DEVKITC_DOUBLE_DOOR_ONLY; ESP32-S3-DevKitC
F230: 1A_SLOW_5X20; Fuseholder_Clip-5x20mm_Bel_FC-203-22_Lateral_P17.80x5.00mm_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
H1, H2, H3, H4: M3.2_NPTH; MountingHole_M3_2_NPTH
HS1A, HS1B, HS2A, HS2B, HS3A, HS3B, HS4A, HS4B, HS5A, HS5B, HS6A, HS6B, HS7A, HS7B, HS8A, HS8B: M3.2 NPTH, TOP HEATSINK; MountingHole_3.2mm_M3
J1: FUSED_12V_CH1; TerminalBlock_Phoenix_MKDS-3-2-5.08_1x02_P5.08mm_Horizontal
J2: FUSED_12V_CH2; TerminalBlock_Phoenix_MKDS-3-2-5.08_1x02_P5.08mm_Horizontal
J3: FUSED_12V_CH3; TerminalBlock_Phoenix_MKDS-3-2-5.08_1x02_P5.08mm_Horizontal
J4: FUSED_12V_CH4; TerminalBlock_Phoenix_MKDS-3-2-5.08_1x02_P5.08mm_Horizontal
J5: FUSED_12V_CH5; TerminalBlock_Phoenix_MKDS-3-2-5.08_1x02_P5.08mm_Horizontal
J6: FUSED_12V_CH6; TerminalBlock_Phoenix_MKDS-3-2-5.08_1x02_P5.08mm_Horizontal
J7: FUSED_12V_CH7; TerminalBlock_Phoenix_MKDS-3-2-5.08_1x02_P5.08mm_Horizontal
J8: FUSED_12V_CH8; TerminalBlock_Phoenix_MKDS-3-2-5.08_1x02_P5.08mm_Horizontal
J9: ACTUATOR_CH1; TerminalBlock_Phoenix_MKDS-3-2-5.08_1x02_P5.08mm_Horizontal
J10: ACTUATOR_CH2; TerminalBlock_Phoenix_MKDS-3-2-5.08_1x02_P5.08mm_Horizontal
J11: ACTUATOR_CH3; TerminalBlock_Phoenix_MKDS-3-2-5.08_1x02_P5.08mm_Horizontal
J12: ACTUATOR_CH4; TerminalBlock_Phoenix_MKDS-3-2-5.08_1x02_P5.08mm_Horizontal
J13: ACTUATOR_CH5; TerminalBlock_Phoenix_MKDS-3-2-5.08_1x02_P5.08mm_Horizontal
J14: ACTUATOR_CH6; TerminalBlock_Phoenix_MKDS-3-2-5.08_1x02_P5.08mm_Horizontal
J15: ACTUATOR_CH7; TerminalBlock_Phoenix_MKDS-3-2-5.08_1x02_P5.08mm_Horizontal
J16: ACTUATOR_CH8; TerminalBlock_Phoenix_MKDS-3-2-5.08_1x02_P5.08mm_Horizontal
J201: REED_A_OPEN_3V3_SIG_GND; TerminalBlock_Phoenix_PT-1,5-3-3.5-H_1x03_P3.50mm_Horizontal
J202: REED_A_CLOSED_3V3_SIG_GND; TerminalBlock_Phoenix_PT-1,5-3-3.5-H_1x03_P3.50mm_Horizontal
J203: REED_A_IN_PLACE_3V3_SIG_GND; TerminalBlock_Phoenix_PT-1,5-3-3.5-H_1x03_P3.50mm_Horizontal
J204: REED_B_OPEN_3V3_SIG_GND; TerminalBlock_Phoenix_PT-1,5-3-3.5-H_1x03_P3.50mm_Horizontal
J205: REED_B_CLOSED_3V3_SIG_GND; TerminalBlock_Phoenix_PT-1,5-3-3.5-H_1x03_P3.50mm_Horizontal
J206: REED_B_IN_PLACE_3V3_SIG_GND; TerminalBlock_Phoenix_PT-1,5-3-3.5-H_1x03_P3.50mm_Horizontal
J211: CAP_CS1_GND; TerminalBlock_Phoenix_PT-1,5-2-3.5-H_1x02_P3.50mm_Horizontal
J212: CAP_CS2_GND; TerminalBlock_Phoenix_PT-1,5-2-3.5-H_1x02_P3.50mm_Horizontal
J213: CAP_CS3_GND; TerminalBlock_Phoenix_PT-1,5-2-3.5-H_1x02_P3.50mm_Horizontal
J214: CAP_CS4_GND; TerminalBlock_Phoenix_PT-1,5-2-3.5-H_1x02_P3.50mm_Horizontal
J215: CAP_CS5_GND; TerminalBlock_Phoenix_PT-1,5-2-3.5-H_1x02_P3.50mm_Horizontal
J216: CAP_CS6_GND; TerminalBlock_Phoenix_PT-1,5-2-3.5-H_1x02_P3.50mm_Horizontal
J217: CAP_CS7_GND; TerminalBlock_Phoenix_PT-1,5-2-3.5-H_1x02_P3.50mm_Horizontal
J218: CAP_CS8_GND; TerminalBlock_Phoenix_PT-1,5-2-3.5-H_1x02_P3.50mm_Horizontal
J220: SWD_S1_3V3_DIO_CLK_NRST_GND; PinHeader_1x05_P2.54mm_Vertical
J230: LOGIC_12V_GND; TerminalBlock_Phoenix_PT-1,5-2-3.5-H_1x02_P3.50mm_Horizontal
J240: CANH_CANL_GND_SHIELD; TerminalBlock_Phoenix_PT-1,5-4-3.5-H_1x04_P3.50mm_Horizontal
L240: CMC_CAN; L_CommonModeChoke_Coilcraft_1812CAN
MOD1: STM32F103C8T6_MINI_SLOT_S1; STM32F103C8T6_Mini_CH340_4x10
MOD2: STM32F103C8T6_MINI_SLOT_S2; STM32F103C8T6_Mini_CH340_4x10
MOD3: STM32F103C8T6_MINI_SLOT_S3; STM32F103C8T6_Mini_CH340_4x10
MOD4: STM32F103C8T6_MINI_SLOT_S4; STM32F103C8T6_Mini_CH340_4x10
R201, R202, R203, R204, R205, R206, R207, R208: 1K_CAP_INPUT; R_0603_1608Metric
R209: 10K_CAP_RESET_PULLDOWN; R_0603_1608Metric
R210: 10K_CAP_IRQ_PULLUP; R_0603_1608Metric
R240: 120R_CAN_TERM_DNP; R_1206_3216Metric
R250, R251, R252, R253, R254, R255: 100R_UART_TX; R_0603_1608Metric
R260: 10K_EEPROM_CS_PULLUP; R_0603_1608Metric
R261: 10K_EEPROM_WP_PULLUP; R_0603_1608Metric
R262: 10K_EEPROM_HOLD_PULLUP; R_0603_1608Metric
R1101, R1201, R1301, R1401, R1501, R1601, R1701, R1801: 100R INA_SER; R_0603_1608Metric
R1102, R1202, R1302, R1402, R1502, R1602, R1702, R1802: 100R INB_SER; R_0603_1608Metric
R1103, R1203, R1303, R1403, R1503, R1603, R1703, R1803: 100R PWM_SER; R_0603_1608Metric
R1104, R1204, R1304, R1404, R1504, R1604, R1704, R1804: 10K INA_PULLDOWN; R_0603_1608Metric
R1105, R1205, R1305, R1405, R1505, R1605, R1705, R1805: 10K INB_PULLDOWN; R_0603_1608Metric
R1106, R1206, R1306, R1406, R1506, R1606, R1706, R1806: 10K PWM_PULLDOWN; R_0603_1608Metric
R1107, R1207, R1307, R1407, R1507, R1607, R1707, R1807: 4K7 DIAG_PULLUP; R_0603_1608Metric
R1108, R1208, R1308, R1408, R1508, R1608, R1708, R1808: 10K CS_DIS_PULLDOWN; R_0603_1608Metric
R1109, R1209, R1309, R1409, R1509, R1609, R1709, R1809: 1K 1% CS_LOAD; R_0603_1608Metric
R1110, R1210, R1310, R1410, R1510, R1610, R1710, R1810: 10K ADC_SERIES; R_0603_1608Metric
R3011: 47K SLOT_S1_ID0; R_0603_1608Metric
R3012: 47K SLOT_S1_ID1; R_0603_1608Metric
R3021: 0R SLOT_S2_ID0; R_0603_1608Metric
R3022: 47K SLOT_S2_ID1; R_0603_1608Metric
R3031: 47K SLOT_S3_ID0; R_0603_1608Metric
R3032: 0R SLOT_S3_ID1; R_0603_1608Metric
R3041: 0R SLOT_S4_ID0; R_0603_1608Metric
R3042: 0R SLOT_S4_ID1; R_0603_1608Metric
RF1: CC1101_433MHZ; CC1101_433MHz_Module_28x15mm_2x04
U1, U2, U3, U4, U5, U6, U7, U8: VNH5019A-E; ST_MultiPowerSO-30
U230: AMS1117-3V3; SOT-223-3_TabPin2
U250: 25LC256_SOIC8_CARRIER_ID; SOIC-8_3.9x4.9mm_P1.27mm

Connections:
CANH_BUS: CAN1.5, CAN2.5, L240.4, R240.1
CANH_ENTRY: D240.1, J240.1, L240.1
CANL_BUS: CAN1.6, CAN2.6, L240.3, R240.2
CANL_ENTRY: D241.1, J240.2, L240.2
CAP_C1_FIELD: J211.1, R201.2
CAP_C1_RAW: CAP1.18, R201.1
CAP_C2_FIELD: J212.1, R202.2
CAP_C2_RAW: CAP1.19, R202.1
CAP_C3_FIELD: J213.1, R203.2
CAP_C3_RAW: CAP1.20, R203.1
CAP_C4_FIELD: J214.1, R204.2
CAP_C4_RAW: CAP1.21, R204.1
CAP_C5_FIELD: J215.1, R205.2
CAP_C5_RAW: CAP1.22, R205.1
CAP_C6_FIELD: J216.1, R206.2
CAP_C6_RAW: CAP1.23, R206.1
CAP_C7_FIELD: J217.1, R207.2
CAP_C7_RAW: CAP1.24, R207.1
CAP_C8_FIELD: J218.1, R208.2
CAP_C8_RAW: CAP1.25, R208.1
CAP_CS: CAP1.15, MOD1.18
CAP_IRQ: MOD1.13, R210.1
CAP_MISO: CAP1.1, MOD1.17, U250.2
CAP_MOSI: CAP1.14, MOD1.7, U250.5
CAP_RESET: CAP1.16, MOD1.29, R209.1
CAP_SCK: CAP1.2, MOD1.8, U250.6
CH1_CS_DIS: R1108.1, U1.6
CH1_CS_RAW: R1109.1, R1110.1, U1.8
CH1_CURRENT_ADC: C1103.1, D1101.3, MOD1.20, R1110.2
CH1_DIAG: MOD1.27, R1107.1, U1.5, U1.9
CH1_INA: R1101.2, R1104.1, U1.4
CH1_INA_MCU: MOD1.2, R1101.1
CH1_INB: R1102.2, R1105.1, U1.10
CH1_INB_MCU: MOD1.12, R1102.1
CH1_OUTA: J9.1, U1.1, U1.25, U1.30
CH1_OUTB: J9.2, U1.15, U1.16, U1.21
CH1_PWM: R1103.2, R1106.1, U1.7
CH1_PWM_MCU: MOD1.22, R1103.1
CH2_CS_DIS: R1208.1, U2.6
CH2_CS_RAW: R1209.1, R1210.1, U2.8
CH2_CURRENT_ADC: C1203.1, D1201.3, MOD1.10, R1210.2
CH2_DIAG: MOD1.3, R1207.1, U2.5, U2.9
CH2_INA: R1201.2, R1204.1, U2.4
CH2_INA_MCU: MOD1.26, R1201.1
CH2_INB: R1202.2, R1205.1, U2.10
CH2_INB_MCU: MOD1.36, R1202.1
CH2_OUTA: J10.1, U2.1, U2.25, U2.30
CH2_OUTB: J10.2, U2.15, U2.16, U2.21
CH2_PWM: R1203.2, R1206.1, U2.7
CH2_PWM_MCU: MOD1.32, R1203.1
CH3_CS_DIS: R1308.1, U3.6
CH3_CS_RAW: R1309.1, R1310.1, U3.8
CH3_CURRENT_ADC: C1303.1, D1301.3, MOD2.20, R1310.2
CH3_DIAG: MOD2.27, R1307.1, U3.5, U3.9
CH3_INA: R1301.2, R1304.1, U3.4
CH3_INA_MCU: MOD2.2, R1301.1
CH3_INB: R1302.2, R1305.1, U3.10
CH3_INB_MCU: MOD2.12, R1302.1
CH3_OUTA: J11.1, U3.1, U3.25, U3.30
CH3_OUTB: J11.2, U3.15, U3.16, U3.21
CH3_PWM: R1303.2, R1306.1, U3.7
CH3_PWM_MCU: MOD2.22, R1303.1
CH4_CS_DIS: R1408.1, U4.6
CH4_CS_RAW: R1409.1, R1410.1, U4.8
CH4_CURRENT_ADC: C1403.1, D1401.3, MOD2.10, R1410.2
CH4_DIAG: MOD2.3, R1407.1, U4.5, U4.9
CH4_INA: R1401.2, R1404.1, U4.4
CH4_INA_MCU: MOD2.26, R1401.1
CH4_INB: R1402.2, R1405.1, U4.10
CH4_INB_MCU: MOD2.36, R1402.1
CH4_OUTA: J12.1, U4.1, U4.25, U4.30
CH4_OUTB: J12.2, U4.15, U4.16, U4.21
CH4_PWM: R1403.2, R1406.1, U4.7
CH4_PWM_MCU: MOD2.32, R1403.1
CH5_CS_DIS: R1508.1, U5.6
CH5_CS_RAW: R1509.1, R1510.1, U5.8
CH5_CURRENT_ADC: C1503.1, D1501.3, MOD3.20, R1510.2
CH5_DIAG: MOD3.27, R1507.1, U5.5, U5.9
CH5_INA: R1501.2, R1504.1, U5.4
CH5_INA_MCU: MOD3.2, R1501.1
CH5_INB: R1502.2, R1505.1, U5.10
CH5_INB_MCU: MOD3.12, R1502.1
CH5_OUTA: J13.1, U5.1, U5.25, U5.30
CH5_OUTB: J13.2, U5.15, U5.16, U5.21
CH5_PWM: R1503.2, R1506.1, U5.7
CH5_PWM_MCU: MOD3.22, R1503.1
CH6_CS_DIS: R1608.1, U6.6
CH6_CS_RAW: R1609.1, R1610.1, U6.8
CH6_CURRENT_ADC: C1603.1, D1601.3, MOD3.10, R1610.2
CH6_DIAG: MOD3.3, R1607.1, U6.5, U6.9
CH6_INA: R1601.2, R1604.1, U6.4
CH6_INA_MCU: MOD3.26, R1601.1
CH6_INB: R1602.2, R1605.1, U6.10
CH6_INB_MCU: MOD3.36, R1602.1
CH6_OUTA: J14.1, U6.1, U6.25, U6.30
CH6_OUTB: J14.2, U6.15, U6.16, U6.21
CH6_PWM: R1603.2, R1606.1, U6.7
CH6_PWM_MCU: MOD3.32, R1603.1
CH7_CS_DIS: R1708.1, U7.6
CH7_CS_RAW: R1709.1, R1710.1, U7.8
CH7_CURRENT_ADC: C1703.1, D1701.3, MOD4.20, R1710.2
CH7_DIAG: MOD4.27, R1707.1, U7.5, U7.9
CH7_INA: R1701.2, R1704.1, U7.4
CH7_INA_MCU: MOD4.2, R1701.1
CH7_INB: R1702.2, R1705.1, U7.10
CH7_INB_MCU: MOD4.12, R1702.1
CH7_OUTA: J15.1, U7.1, U7.25, U7.30
CH7_OUTB: J15.2, U7.15, U7.16, U7.21
CH7_PWM: R1703.2, R1706.1, U7.7
CH7_PWM_MCU: MOD4.22, R1703.1
CH8_CS_DIS: R1808.1, U8.6
CH8_CS_RAW: R1809.1, R1810.1, U8.8
CH8_CURRENT_ADC: C1803.1, D1801.3, MOD4.10, R1810.2
CH8_DIAG: MOD4.3, R1807.1, U8.5, U8.9
CH8_INA: R1801.2, R1804.1, U8.4
CH8_INA_MCU: MOD4.26, R1801.1
CH8_INB: R1802.2, R1805.1, U8.10
CH8_INB_MCU: MOD4.36, R1802.1
CH8_OUTA: J16.1, U8.1, U8.25, U8.30
CH8_OUTB: J16.2, U8.15, U8.16, U8.21
CH8_PWM: R1803.2, R1806.1, U8.7
CH8_PWM_MCU: MOD4.32, R1803.1
EEPROM_CS: MOD1.35, R260.1, U250.1
EEPROM_HOLD: R262.1, U250.7
EEPROM_WP: R261.1, U250.3
ESP_CAN_RX_GPIO38: CAN2.4, ESP1.35
ESP_CAN_TX_GPIO39: CAN2.3, ESP1.36
FUSED_12V_CH1: C1101.1, C1102.1, J1.1, U1.3, U1.12, U1.13, U1.23
FUSED_12V_CH2: C1201.1, C1202.1, J2.1, U2.3, U2.12, U2.13, U2.23
FUSED_12V_CH3: C1301.1, C1302.1, J3.1, U3.3, U3.12, U3.13, U3.23
FUSED_12V_CH4: C1401.1, C1402.1, J4.1, U4.3, U4.12, U4.13, U4.23
FUSED_12V_CH5: C1501.1, C1502.1, J5.1, U5.3, U5.12, U5.13, U5.23
FUSED_12V_CH6: C1601.1, C1602.1, J6.1, U6.3, U6.12, U6.13, U6.23
FUSED_12V_CH7: C1701.1, C1702.1, J7.1, U7.3, U7.12, U7.13, U7.23
FUSED_12V_CH8: C1801.1, C1802.1, J8.1, U8.3, U8.12, U8.13, U8.23
GND: C230.2, C231.2, C232.2, C233.2, C234.2, C235.2, C236.2, C237.2, C238.2, C239.2, C250.2, C1101.2, C1102.2, C1103.2, C1201.2, C1202.2, C1203.2, C1301.2, C1302.2, C1303.2, C1401.2, C1402.2, C1403.2, C1501.2, C1502.2, C1503.2, C1601.2, C1602.2, C1603.2, C1701.2, C1702.2, C1703.2, C1801.2, C1802.2, C1803.2, CAN1.2, CAN2.2, CAP1.4, CAP1.26, D231.2, D240.2, D241.2, D1101.1, D1201.1, D1301.1, D1401.1, D1501.1, D1601.1, D1701.1, D1801.1, DC1.2, DC1.4, ESP1.22, ESP1.23, ESP1.24, ESP1.44, J1.2, J2.2, J3.2, J4.2, J5.2, J6.2, J7.2, J8.2, J201.3, J202.3, J203.3, J204.3, J205.3, J206.3, J211.2, J212.2, J213.2, J214.2, J215.2, J216.2, J217.2, J218.2, J220.5, J230.2, J240.3, J240.4, MOD1.1, MOD1.31, MOD2.1, MOD2.31, MOD3.1, MOD3.31, MOD4.1, MOD4.31, R209.2, R1104.2, R1105.2, R1106.2, R1108.2, R1109.2, R1204.2, R1205.2, R1206.2, R1208.2, R1209.2, R1304.2, R1305.2, R1306.2, R1308.2, R1309.2, R1404.2, R1405.2, R1406.2, R1408.2, R1409.2, R1504.2, R1505.2, R1506.2, R1508.2, R1509.2, R1604.2, R1605.2, R1606.2, R1608.2, R1609.2, R1704.2, R1705.2, R1706.2, R1708.2, R1709.2, R1804.2, R1805.2, R1806.2, R1808.2, R1809.2, R3021.2, R3032.2, R3041.2, R3042.2, RF1.4, U1.18, U1.19, U1.20, U1.26, U1.27, U1.28, U2.18, U2.19, U2.20, U2.26, U2.27, U2.28, U3.18, U3.19, U3.20, U3.26, U3.27, U3.28, U4.18, U4.19, U4.20, U4.26, U4.27, U4.28, U5.18, U5.19, U5.20, U5.26, U5.27, U5.28, U6.18, U6.19, U6.20, U6.26, U6.27, U6.28, U7.18, U7.19, U7.20, U7.26, U7.27, U7.28, U8.18, U8.19, U8.20, U8.26, U8.27, U8.28, U230.1, U250.4
LOGIC_3V3: C238.1, C239.1, C250.1, CAN1.1, CAN2.1, R260.2, R261.2, R262.2, RF1.2, U230.2, U250.8
LOGIC_5V: C233.1, C234.1, C235.1, C236.1, C237.1, CAP1.3, DC1.3, ESP1.21, MOD1.21, MOD2.21, MOD3.21, MOD4.21, U230.3
LOGIC_12V_FUSED: D230.1, F230.2
LOGIC_12V_IN: F230.1, J230.1
LOGIC_12V_PROTECTED: C230.1, C231.1, C232.1, D230.2, D231.1, DC1.1
REED_A_CLOSED: J202.2, MOD1.5
REED_A_IN_PLACE: J203.2, MOD1.38
REED_A_OPEN: J201.2, MOD1.6
REED_B_CLOSED: J205.2, MOD2.5
REED_B_IN_PLACE: J206.2, MOD2.38
REED_B_OPEN: J204.2, MOD2.6
RF_CSN: ESP1.16, RF1.3
RF_GDO0: ESP1.4, RF1.1
RF_GDO2: ESP1.5, RF1.8
RF_MISO: ESP1.19, RF1.7
RF_MOSI: ESP1.17, RF1.6
RF_SCK: ESP1.18, RF1.5
S1_3V3: D1101.2, D1201.2, J201.1, J202.1, J203.1, J220.1, MOD1.11, R210.2, R1107.2, R1207.2, R3011.2, R3012.2
S1_CAN_RX: CAN1.4, MOD1.33
S1_CAN_TX: CAN1.3, MOD1.24
S1_NRST: J220.4, MOD1.16
S1_SLOT_ID0: MOD1.15, R3011.1
S1_SWCLK: J220.3, MOD1.25
S1_SWDIO: J220.2, MOD1.34
S1_UART1_RX: MOD1.28, R251.2
S1_UART1_TX: MOD1.37, R250.1
S1_UART2_RX: MOD1.9, R253.2
S1_UART2_TX: MOD1.19, R252.1
S1_UART3_RX: MOD1.14, R255.2
S1_UART3_TX: MOD1.4, R254.1
S2_3V3: D1301.2, D1401.2, J204.1, J205.1, J206.1, MOD2.11, R1307.2, R1407.2, R3022.2
S2_SLOT_ID0: MOD2.15, R3021.1
S2_SLOT_ID1: MOD2.7, R3022.1
S2_UART_RX: MOD2.28, R250.2
S2_UART_TX: MOD2.37, R251.1
S3_3V3: D1501.2, D1601.2, MOD3.11, R1507.2, R1607.2, R3031.2
S3_SLOT_ID0: MOD3.15, R3031.1
S3_SLOT_ID1: MOD3.7, R3032.1
S3_UART_RX: MOD3.28, R252.2
S3_UART_TX: MOD3.37, R253.1
S4_3V3: D1701.2, D1801.2, MOD4.11, R1707.2, R1807.2
S4_SLOT_ID0: MOD4.15, R3041.1
S4_SLOT_ID1: MOD4.7, R3042.1
S4_UART_RX: MOD4.28, R254.2
S4_UART_TX: MOD4.37, R255.1

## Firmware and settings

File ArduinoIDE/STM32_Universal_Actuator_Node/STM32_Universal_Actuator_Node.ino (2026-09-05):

#include <Arduino.h>
#include <EEPROM.h>
#include <IWatchdog.h>
#include <SPI.h>
#include <WindowBusProtocol.h>

#include "BxCan.h"
#include "Cap1188Spi.h"
#include "CarrierStore.h"
#include "LocalLink.h"
#include "config.h"

using namespace windowbus;

namespace {

constexpr uint32_t CONFIG_MAGIC = 0x31474643u;  // CFG1
constexpr uint8_t CONFIG_VERSION = 2;

enum class Direction : uint8_t { None, Extend, Retract };

#pragma pack(push, 1)
struct NodeConfig {
  uint32_t magic;
  uint8_t version;
  uint8_t autoAdapt;
  uint8_t capEnabledMask;
  uint16_t revision;
  uint16_t maxCurrentMa[2];
  uint16_t zeroCurrentMa[2];
  uint16_t pwmOpenPermille[2];
  uint16_t pwmClosePermille[2];
  uint16_t lastOpenMs[2];
  uint16_t lastCloseMs[2];
  uint16_t minTravelMs;
  uint16_t endstopConfirmMs;
  uint32_t maxTravelMs;
  uint16_t crc;
};
#pragma pack(pop)

static_assert(sizeof(NodeConfig) == 43, "Changing NodeConfig requires an EEPROM migration");

struct ActuatorRuntime {
  Direction direction = Direction::None;
  uint16_t currentMa = 0;
  uint16_t filteredCurrentMa = 0;
  uint16_t pwmPermille = 0;
  uint8_t flags = ACTUATOR_DIAG_OK;
  uint32_t startedAt = 0;
  uint32_t overCurrentSince = 0;
  uint32_t zeroCurrentSince = 0;
  uint32_t earlyZeroSince = 0;
  bool moving = false;
  bool finished = false;
};

HardwareSerial uartPort1(hw::UART1_RX, hw::UART1_TX);
HardwareSerial uartPort2(hw::UART2_RX, hw::UART2_TX);
HardwareSerial uartPort3(hw::UART3_RX, hw::UART3_TX);
LocalLink localLinks[hw::SLAVE_COUNT] = {LocalLink(uartPort1), LocalLink(uartPort2), LocalLink(uartPort3)};

BxCan canBus;
Cap1188Spi cap1188(hw::CAP_CS, hw::CAP_RESET);
CarrierStore carrierStore(hw::CABINET_EEPROM_CS);

BoardRole boardRole = BoardRole::Master;
CarrierIdentity carrier = {};
NodeConfig config = {};
ActuatorRuntime actuators[2];
LocalStatusPayload slaveStatus[hw::SLAVE_COUNT] = {};
LocalConfigPayload slaveConfigs[hw::SLAVE_COUNT] = {};
uint32_t slaveLastSeen[hw::SLAVE_COUNT] = {};
uint8_t slaveTxSequence[hw::SLAVE_COUNT] = {};

RunState runState = RunState::Boot;
Position position = Position::Unknown;
Fault fault = Fault::NotConfigured;
Command activeCommand = Command::None;
Command lastMovementCommand = Command::None;
uint8_t faultActuator = 0;
uint8_t bootId = 0;
uint8_t lastCommandSequence = 0xFF;
uint8_t reedMask = 0;
uint8_t capMask = 0;
uint32_t uidHash = 0;
uint32_t lastCommandAt = 0;
uint32_t armedUntil = 0;
uint32_t lastControlAt = 0;
uint32_t lastSensorAt = 0;
uint32_t lastCapHealthAt = 0;
uint32_t lastStatusAt = 0;
uint32_t lastDiscoveryAt = 0;
bool carrierConfigured = false;
bool canOnline = false;
bool capOnline = false;
bool calibrationPendingApply = false;
bool configStorageHealthy = true;
PowerLossRecord powerLossRecord = {};
bool powerLossEventPending = false;
bool powerLossHandled = false;
uint32_t lastPowerEventAttempt = 0;

void sendCanSensors();

uint16_t configCrc(NodeConfig value) {
  value.crc = 0;
  return crc16(reinterpret_cast<const uint8_t *>(&value), sizeof(value));
}

void setDefaultConfig() {
  memset(&config, 0, sizeof(config));
  config.magic = CONFIG_MAGIC;
  config.version = CONFIG_VERSION;
  config.revision = 1;
  config.autoAdapt = 1;
  config.capEnabledMask = 0x07;
  for (uint8_t i = 0; i < 2; ++i) {
    config.maxCurrentMa[i] = hw::DEFAULT_MAX_CURRENT_MA;
    config.zeroCurrentMa[i] = hw::DEFAULT_ZERO_CURRENT_MA;
    config.pwmOpenPermille[i] = hw::DEFAULT_PWM_PERMILLE;
    config.pwmClosePermille[i] = hw::DEFAULT_PWM_PERMILLE;
  }
  config.minTravelMs = hw::DEFAULT_MIN_TRAVEL_MS;
  config.endstopConfirmMs = hw::ENDSTOP_CONFIRM_MS;
  config.maxTravelMs = hw::DEFAULT_MAX_TRAVEL_MS;
  config.crc = configCrc(config);
}

bool loadConfig() {
  EEPROM.get(0, config);
  if (config.magic != CONFIG_MAGIC || config.version != CONFIG_VERSION || config.crc != configCrc(config)) {
    setDefaultConfig();
    return false;
  }
  return true;
}

bool saveConfig() {
  config.magic = CONFIG_MAGIC;
  config.version = CONFIG_VERSION;
  config.crc = configCrc(config);
  for (uint8_t attempt = 0; attempt < hw::EEPROM_SAVE_RETRIES; ++attempt) {
    EEPROM.put(0, config);
    NodeConfig verify = {};
    EEPROM.get(0, verify);
    if (verify.magic == CONFIG_MAGIC && verify.version == CONFIG_VERSION &&
        verify.crc == configCrc(verify) && memcmp(&verify, &config, sizeof(config)) == 0) {
      configStorageHealthy = true;
      return true;
    }
    delay(2);
  }
  configStorageHealthy = false;
  return false;
}

uint32_t readUidHash() {
  const volatile uint32_t *uid = reinterpret_cast<const volatile uint32_t *>(UID_BASE);
  uint32_t hash = 2166136261u;
  for (uint8_t word = 0; word < 3; ++word) {
    uint32_t value = uid[word];
    for (uint8_t byte = 0; byte < 4; ++byte) {
      hash ^= static_cast<uint8_t>(value);
      hash *= 16777619u;
      value >>= 8;
    }
  }
  return hash;
}

BoardRole readBoardRole() {
  pinMode(hw::SLOT_ID0, INPUT_PULLUP);
  pinMode(hw::SLOT_ID1, INPUT_PULLUP);
  delay(2);
  const uint8_t value = (digitalRead(hw::SLOT_ID0) == LOW ? 1u : 0u) |
                        (digitalRead(hw::SLOT_ID1) == LOW ? 2u : 0u);
  return static_cast<BoardRole>(value);
}

uint8_t roleIndex() {
  return static_cast<uint8_t>(boardRole);
}

bool isMaster() {
  return boardRole == BoardRole::Master;
}

bool supportedCommand(uint8_t value) {
  if (!validCommand(value)) return false;
  switch (static_cast<Command>(value)) {
    case Command::Open:
    case Command::Close:
    case Command::Stop:
    case Command::Arm:
    case Command::ClearFault:
    case Command::CalibrateOpen:
    case Command::CalibrateClose:
    case Command::ResetCalibration:
    case Command::ConfigureCap1188:
      return true;
    default:
      return false;
  }
}

Direction commandDirection(Command command) {
  switch (command) {
    case Command::Open:
    case Command::CalibrateOpen:
      return Direction::Extend;
    case Command::Close:
    case Command::CalibrateClose:
      return Direction::Retract;
    default:
      return Direction::None;
  }
}

uint16_t commandPwm(uint8_t actuator, Command command) {
  if (command == Command::CalibrateOpen || command == Command::CalibrateClose) return hw::PWM_MAX;
  return commandDirection(command) == Direction::Extend
             ? config.pwmOpenPermille[actuator]
             : config.pwmClosePermille[actuator];
}

void writePwm(uint8_t index, uint16_t permille) {
  permille = min<uint16_t>(permille, hw::PWM_MAX);
  const uint32_t duty = (static_cast<uint32_t>(permille) * 1023u) / hw::PWM_MAX;
  analogWrite(hw::PWM_PINS[index], duty);
  actuators[index].pwmPermille = permille;
}

void stopActuator(uint8_t index) {
  writePwm(index, 0);
  digitalWrite(hw::INA_PINS[index], LOW);
  digitalWrite(hw::INB_PINS[index], LOW);
  actuators[index].moving = false;
  actuators[index].direction = Direction::None;
  actuators[index].flags &= static_cast<uint8_t>(~(ACTUATOR_MOVING | ACTUATOR_EXTEND));
}

void stopLocal() {
  for (uint8_t i = 0; i < 2; ++i) stopActuator(i);
}

void refreshCalibrationFlags() {
  for (uint8_t i = 0; i < 2; ++i) {
    if (config.lastOpenMs[i] != 0 && config.lastCloseMs[i] != 0) {
      actuators[i].flags |= ACTUATOR_CALIBRATED;
    } else {
      actuators[i].flags &= static_cast<uint8_t>(~ACTUATOR_CALIBRATED);
    }
  }
}

void startActuator(uint8_t index, Direction direction, uint16_t pwmPermille) {
  stopActuator(index);
  delay(hw::DIRECTION_DEADTIME_MS);
  digitalWrite(hw::INA_PINS[index], direction == Direction::Extend ? HIGH : LOW);
  digitalWrite(hw::INB_PINS[index], direction == Direction::Retract ? HIGH : LOW);
  actuators[index].direction = direction;
  actuators[index].startedAt = millis();
  actuators[index].overCurrentSince = 0;
  actuators[index].zeroCurrentSince = 0;
  actuators[index].earlyZeroSince = 0;
  actuators[index].moving = true;
  actuators[index].finished = false;
  actuators[index].flags = ACTUATOR_MOVING | ACTUATOR_DIAG_OK;
  if (config.lastOpenMs[index] != 0 && config.lastCloseMs[index] != 0) {
    actuators[index].flags |= ACTUATOR_CALIBRATED;
  }
  if (direction == Direction::Extend) actuators[index].flags |= ACTUATOR_EXTEND;
  writePwm(index, pwmPermille);
}

void sendStopToSlaves();
void configureReedInputs();

void setFault(Fault value, uint8_t actuator = 0) {
  stopLocal();
  if (isMaster()) sendStopToSlaves();
  fault = value;
  faultActuator = actuator;
  runState = RunState::Fault;
  activeCommand = Command::None;
}

void clearFault() {
  stopLocal();
  if (!configStorageHealthy && !saveConfig()) {
    setFault(Fault::ConfigStorage);
    return;
  }
  if (isMaster() && config.capEnabledMask != 0 && !capOnline) {
    capOnline = cap1188.begin(config.capEnabledMask);
    if (!capOnline) {
      setFault(Fault::Cap1188Offline);
      return;
    }
  }
  fault = carrierConfigured || !isMaster() ? Fault::None : Fault::NotConfigured;
  faultActuator = 0;
  runState = fault == Fault::None ? RunState::Safe : RunState::Fault;
  activeCommand = Command::None;
}

bool applyConfigPayload(const LocalConfigPayload &payload) {
  carrier.reserved = payload.reedPolarityMask & 0x07u;
  configureReedInputs();
  config.revision = payload.revision;
  config.minTravelMs = payload.minTravelMs;
  config.endstopConfirmMs = payload.endstopConfirmMs;
  config.maxTravelMs = payload.maxTravelMs;
  for (uint8_t i = 0; i < 2; ++i) {
    config.maxCurrentMa[i] = payload.maxCurrentMa[i];
    config.zeroCurrentMa[i] = payload.zeroCurrentMa[i];
    config.pwmOpenPermille[i] = constrain(payload.pwmOpenPermille[i], hw::MIN_CALIBRATION_PWM_PERMILLE, hw::PWM_MAX);
    config.pwmClosePermille[i] = constrain(payload.pwmClosePermille[i], hw::MIN_CALIBRATION_PWM_PERMILLE, hw::PWM_MAX);
  }
  if (!saveConfig()) {
    setFault(Fault::ConfigStorage);
    return false;
  }
  return true;
}

LocalConfigPayload makeConfigPayload() {
  LocalConfigPayload payload = {};
  payload.revision = config.revision;
  payload.minTravelMs = config.minTravelMs;
  payload.endstopConfirmMs = config.endstopConfirmMs;
  payload.maxTravelMs = config.maxTravelMs;
  payload.reedPolarityMask = carrier.reserved & 0x07u;
  for (uint8_t i = 0; i < 2; ++i) {
    payload.maxCurrentMa[i] = config.maxCurrentMa[i];
    payload.zeroCurrentMa[i] = config.zeroCurrentMa[i];
    payload.pwmOpenPermille[i] = config.pwmOpenPermille[i];
    payload.pwmClosePermille[i] = config.pwmClosePermille[i];
  }
  return payload;
}

void forwardCommandToSlaves(Command command, uint8_t flags, uint16_t argument) {
  LocalCommandPayload payload = {
    static_cast<uint8_t>(command), flags, argument, config.revision
  };
  for (uint8_t i = 0; i < carrier.slaveCount; ++i) {
    localLinks[i].send(UartType::Command, ++slaveTxSequence[i], &payload, sizeof(payload));
  }
}

void sendStopToSlaves() {
  for (uint8_t i = 0; i < carrier.slaveCount; ++i) {
    localLinks[i].send(UartType::Stop, ++slaveTxSequence[i], nullptr, 0);
  }
}

void executeCommand(Command command, uint8_t flags, uint16_t argument, bool fromMaster) {
  const uint32_t now = millis();
  lastCommandAt = now;

  if (command == Command::ConfigureCap1188 && isMaster()) {
    config.capEnabledMask = static_cast<uint8_t>(argument) & 0x07u;
    ++config.revision;
    if (!saveConfig()) {
      setFault(Fault::ConfigStorage);
      return;
    }
    if (capOnline) cap1188.setEnabledMask(config.capEnabledMask);
    capMask &= config.capEnabledMask;
    return;
  }

  if (command == Command::Stop) {
    stopLocal();
    if (isMaster()) sendStopToSlaves();
    activeCommand = Command::None;
    runState = RunState::Idle;
    return;
  }
  if (command == Command::ClearFault) {
    clearFault();
    if (isMaster()) forwardCommandToSlaves(command, flags, argument);
    return;
  }
  if (command == Command::ResetCalibration) {
    stopLocal();
    memset(config.lastOpenMs, 0, sizeof(config.lastOpenMs));
    memset(config.lastCloseMs, 0, sizeof(config.lastCloseMs));
    for (uint8_t i = 0; i < 2; ++i) {
      config.pwmOpenPermille[i] = hw::PWM_MAX;
      config.pwmClosePermille[i] = hw::PWM_MAX;
    }
    ++config.revision;
    if (!saveConfig()) {
      setFault(Fault::ConfigStorage);
      return;
    }
    if (isMaster()) {
      for (uint8_t slot = 0; slot < carrier.slaveCount; ++slot) {
        for (uint8_t i = 0; i < 2; ++i) {
          slaveConfigs[slot].pwmOpenPermille[i] = hw::PWM_MAX;
          slaveConfigs[slot].pwmClosePermille[i] = hw::PWM_MAX;
        }
        ++slaveConfigs[slot].revision;
      }
    }
    refreshCalibrationFlags();
    activeCommand = Command::None;
    runState = RunState::Idle;
    if (isMaster() && !fromMaster) forwardCommandToSlaves(command, flags, argument);
    return;
  }
  if (command == Command::Arm) {
    armedUntil = now + hw::COMMAND_ARM_WINDOW_MS;
    if (runState == RunState::Safe) runState = RunState::Idle;
    if (isMaster()) forwardCommandToSlaves(command, flags, argument);
    return;
  }

  const bool armed = static_cast<int32_t>(armedUntil - now) > 0 || (flags & COMMAND_FLAG_ARMED);
  if (!armed || fault != Fault::None || (isMaster() && !carrierConfigured)) return;

  const Direction direction = commandDirection(command);
  if (direction == Direction::None) return;
  if (activeCommand == command && (runState == RunState::Moving || runState == RunState::Calibrating)) return;

  if (isMaster() && config.capEnabledMask != 0) {
    capOnline = cap1188.checkOnline(config.capEnabledMask);
    if (!capOnline) {
      setFault(Fault::Cap1188Offline);
      return;
    }
    capMask = cap1188.touched() & config.capEnabledMask;
    if (direction == Direction::Retract && capMask != 0) {
      setFault(Fault::SafetyEdge);
      return;
    }
  }

  activeCommand = command;
  lastMovementCommand = command;
  runState = (command == Command::CalibrateOpen || command == Command::CalibrateClose)
               ? RunState::Calibrating
               : RunState::Moving;
  calibrationPendingApply = runState == RunState::Calibrating;
  for (uint8_t i = 0; i < 2; ++i) startActuator(i, direction, commandPwm(i, command));
  if (isMaster() && !fromMaster) forwardCommandToSlaves(command, flags | COMMAND_FLAG_ARMED, argument);
}

void updateCurrent(uint8_t index) {
  const uint16_t raw = analogRead(hw::CURRENT_PINS[index]);
  const uint32_t ma = (static_cast<uint32_t>(raw) * hw::CURRENT_MA_PER_ADC_COUNT_NUM) /
                      hw::CURRENT_MA_PER_ADC_COUNT_DEN;
  actuators[index].currentMa = min<uint32_t>(ma, 65535u);
  if (actuators[index].filteredCurrentMa == 0) actuators[index].filteredCurrentMa = actuators[index].currentMa;
  else actuators[index].filteredCurrentMa = static_cast<uint16_t>(
    (static_cast<uint32_t>(actuators[index].filteredCurrentMa) * 7u + actuators[index].currentMa) / 8u);
}

void finishActuatorAtEndstop(uint8_t index, uint32_t now) {
  const uint32_t travel = now - actuators[index].startedAt;
  const uint16_t stored = static_cast<uint16_t>(min<uint32_t>(travel, 65535u));
  if (actuators[index].direction == Direction::Extend) config.lastOpenMs[index] = stored;
  else if (actuators[index].direction == Direction::Retract) config.lastCloseMs[index] = stored;
  actuators[index].flags |= ACTUATOR_ENDSTOP;
  refreshCalibrationFlags();
  actuators[index].finished = true;
  stopActuator(index);
}

void updateActuatorProtection(uint8_t index, uint32_t now) {
  auto &actuator = actuators[index];
  if (!actuator.moving) return;

  const bool diagOk = digitalRead(hw::DIAG_PINS[index]) == HIGH;
  if (diagOk) actuator.flags |= ACTUATOR_DIAG_OK;
  else {
    actuator.flags &= static_cast<uint8_t>(~ACTUATOR_DIAG_OK);
    setFault(Fault::DriverDiagnostic, index + 1);
    return;
  }

  if (actuator.filteredCurrentMa > config.maxCurrentMa[index]) {
    if (actuator.overCurrentSince == 0) actuator.overCurrentSince = now;
    if (now - actuator.overCurrentSince >= hw::OVERCURRENT_CONFIRM_MS) {
      actuator.flags |= ACTUATOR_OVERCURRENT;
      setFault(Fault::OverCurrent, index + 1);
      return;
    }
  } else {
    actuator.overCurrentSince = 0;
  }

  const uint32_t elapsed = now - actuator.startedAt;
  const bool zero = actuator.filteredCurrentMa <= config.zeroCurrentMa[index];
  if (zero) {
    if (actuator.zeroCurrentSince == 0) actuator.zeroCurrentSince = now;
  } else {
    actuator.zeroCurrentSince = 0;
    actuator.earlyZeroSince = 0;
  }

  if (elapsed >= config.minTravelMs && actuator.zeroCurrentSince != 0 &&
      now - actuator.zeroCurrentSince >= config.endstopConfirmMs) {
    finishActuatorAtEndstop(index, now);
    return;
  }

  if (elapsed >= hw::NO_CURRENT_STARTUP_MS && elapsed < config.minTravelMs && zero) {
    if (actuator.earlyZeroSince == 0) actuator.earlyZeroSince = now;
    if (now - actuator.earlyZeroSince >= config.endstopConfirmMs) {
      actuator.flags |= ACTUATOR_NO_CURRENT;
      setFault(Fault::NoCurrent, index + 1);
      return;
    }
  }

  if (elapsed >= config.maxTravelMs) setFault(Fault::MovementTimeout, index + 1);
}

bool localMovementFinished() {
  return !actuators[0].moving && !actuators[1].moving && actuators[0].finished && actuators[1].finished;
}

bool cabinetMovementFinished() {
  if (!localMovementFinished()) return false;
  if (!isMaster()) return true;
  for (uint8_t i = 0; i < carrier.slaveCount; ++i) {
    if (millis() - slaveLastSeen[i] > hw::SLAVE_TIMEOUT_MS) return false;
    if (slaveStatus[i].state == static_cast<uint8_t>(RunState::Moving) ||
        slaveStatus[i].state == static_cast<uint8_t>(RunState::Calibrating)) return false;
  }
  return true;
}

void sendConfigToSlave(uint8_t slot) {
  if (slot >= carrier.slaveCount) return;
  LocalConfigPayload payload = slaveConfigs[slot];
  payload.reedPolarityMask = static_cast<uint8_t>((carrier.reserved >> ((slot + 1u) * 3u)) & 0x07u);
  localLinks[slot].send(UartType::Config, ++slaveTxSequence[slot], &payload, sizeof(payload));
}

void handlePowerFailure() {
  if (!isMaster() || powerLossHandled || digitalRead(hw::POWER_GOOD) != LOW) return;
  powerLossHandled = true;

  PowerLossRecord record = {};
  record.uptimeMs = millis();
  record.sequence = static_cast<uint8_t>(powerLossRecord.sequence + 1u);
  record.runState = static_cast<uint8_t>(runState);
  record.command = static_cast<uint8_t>(activeCommand);
  record.fault = static_cast<uint8_t>(fault);
  record.actuator = faultActuator;

  stopLocal();
  sendStopToSlaves();
  digitalWrite(hw::CAP_CS, HIGH);
  if (carrierStore.savePowerLoss(record)) {
    powerLossRecord = record;
    powerLossRecord.pending = 1;
    powerLossEventPending = true;
  }
  setFault(Fault::LowSupply);
}

void sendPendingPowerEvent() {
  if (!isMaster() || !powerLossEventPending || !carrierConfigured || !canOnline ||
      digitalRead(hw::POWER_GOOD) == LOW || millis() - lastPowerEventAttempt < 1000) return;
  lastPowerEventAttempt = millis();
  const CanEventFrame event = {
    PROTOCOL_VERSION,
    powerLossRecord.sequence,
    static_cast<uint8_t>(Fault::PowerRecovered),
    powerLossRecord.actuator,
    powerLossRecord.uptimeMs,
  };
  if (canBus.send(CAN_EVENT_BASE + carrier.cabinetId, &event, sizeof(event)) &&
      carrierStore.acknowledgePowerLoss(powerLossRecord)) {
    powerLossRecord.pending = 0;
    powerLossEventPending = false;
    powerLossHandled = false;
  }
}
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
void loop() {
  uint32_t now = millis();
  IWatchdog.reload();

  if (isMaster() && digitalRead(hw::POWER_GOOD) == LOW) {
    handlePowerFailure();
    delay(1);
    return;
  }

  if (isMaster()) {
    pollCan();
    pollMasterLinks();
    sendPendingPowerEvent();
  } else {
    pollSlaveLink();
  }

  // Command handlers may spend time in direction dead-time; protection must use a newer timestamp.
  now = millis();

  if (now - lastSensorAt >= hw::SENSOR_PERIOD_MS) {
    lastSensorAt = now;
    for (uint8_t i = 0; i < 2; ++i) updateCurrent(i);
    if (isMaster()) readMasterSensors();
    else reedMask = readLocalReeds();
  }

  if (now - lastControlAt >= hw::CONTROL_PERIOD_MS) {
    lastControlAt = now;
    for (uint8_t i = 0; i < 2; ++i) updateActuatorProtection(i, now);
    completeMovementIfReady();
    if ((runState == RunState::Moving || runState == RunState::Calibrating) &&
        now - lastCommandAt > hw::HEARTBEAT_TIMEOUT_MS) {
      setFault(Fault::CommunicationTimeout);
    }
  }

  const uint32_t statusPeriod = (runState == RunState::Moving || runState == RunState::Calibrating)
                                  ? hw::STATUS_PERIOD_MOVING_MS
                                  : hw::STATUS_PERIOD_IDLE_MS;
  if (now - lastStatusAt >= statusPeriod) {
    lastStatusAt = now;
    if (isMaster()) sendCanTelemetry();
    else sendSlaveStatus();
  }
}

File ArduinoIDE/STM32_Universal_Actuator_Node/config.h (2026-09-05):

#pragma once

#include <Arduino.h>

namespace hw {

constexpr char FW_VERSION[] = "0.1.0-alpha.15";
constexpr uint32_t FW_BUILD = 15;

constexpr uint8_t ACTUATOR_COUNT = 2;
constexpr uint8_t SLAVE_COUNT = 3;

// Slot identity is provided by the carrier. PA7 is sampled before SPI starts;
// only slave slots that do not use CAP1188 strap it low.
constexpr PinName SLOT_ID0 = PB_2;
constexpr PinName SLOT_ID1 = PA_7;

// VNH5019A-E current sense inputs.
constexpr PinName CURRENT_PINS[ACTUATOR_COUNT] = {PA_0, PA_1};

// Two hardware PWM outputs from TIM1.
constexpr PinName PWM_PINS[ACTUATOR_COUNT] = {PA_8, PA_9};
constexpr PinName INA_PINS[ACTUATOR_COUNT] = {PB_14, PB_3};
constexpr PinName INB_PINS[ACTUATOR_COUNT] = {PB_15, PB_4};
constexpr PinName DIAG_PINS[ACTUATOR_COUNT] = {PB_5, PB_12};

// Master-only peripherals.
constexpr PinName REED_PINS[3] = {PB_0, PB_1, PB_8};
constexpr PinName CAP_CS = PA_4;
constexpr PinName CAP_IRQ = PB_13;
constexpr PinName CAP_RESET = PB_9;
constexpr PinName CABINET_EEPROM_CS = PA_15;
// Open-drain output from a 12 V supervisor/comparator on the carrier, low = supply bad.
constexpr PinName POWER_GOOD = PC_13;

// CAN uses the default bxCAN mapping: PA11 RX, PA12 TX.
constexpr PinName CAN_RX = PA_11;
constexpr PinName CAN_TX = PA_12;

// Master has three direct point-to-point UART links. Every slave uses PB6/PB7 upstream.
constexpr PinName UART1_RX = PB_7;
constexpr PinName UART1_TX = PB_6;
constexpr PinName UART2_RX = PA_3;
constexpr PinName UART2_TX = PA_2;
constexpr PinName UART3_RX = PB_11;
constexpr PinName UART3_TX = PB_10;

constexpr uint32_t LOCAL_UART_BAUD = 250000;
constexpr uint32_t CAN_BITRATE = 500000;
constexpr uint8_t CAN_RX_BUDGET_PER_LOOP = 20;
constexpr uint8_t UART_RX_BUDGET_PER_LINK = 10;
constexpr uint8_t EEPROM_SAVE_RETRIES = 3;
constexpr uint32_t PWM_FREQUENCY_HZ = 20000;
constexpr uint16_t PWM_MAX = 1000;

constexpr uint32_t CONTROL_PERIOD_MS = 5;
constexpr uint32_t SENSOR_PERIOD_MS = 10;
constexpr uint32_t CAP_HEALTH_PERIOD_MS = 250;
constexpr uint32_t STATUS_PERIOD_MOVING_MS = 100;
constexpr uint32_t STATUS_PERIOD_IDLE_MS = 1000;
constexpr uint32_t HEARTBEAT_TIMEOUT_MS = 300;
constexpr uint32_t SLAVE_TIMEOUT_MS = 400;
constexpr uint32_t COMMAND_ARM_WINDOW_MS = 1000;
constexpr uint32_t DIRECTION_DEADTIME_MS = 30;
constexpr uint32_t OVERCURRENT_CONFIRM_MS = 60;
constexpr uint32_t NO_CURRENT_STARTUP_MS = 700;
constexpr uint32_t ENDSTOP_CONFIRM_MS = 250;
constexpr uint32_t DEFAULT_MAX_TRAVEL_MS = 45000;
constexpr uint32_t DEFAULT_MIN_TRAVEL_MS = 1500;
constexpr uint16_t DEFAULT_MAX_CURRENT_MA = 5000;
constexpr uint16_t DEFAULT_ZERO_CURRENT_MA = 100;
constexpr uint16_t DEFAULT_PWM_PERMILLE = 1000;
constexpr uint16_t MIN_CALIBRATION_PWM_PERMILLE = 600;
constexpr uint16_t LOW_SUPPLY_MV = 9500;

// Theoretical starting value for K0=7110, 1 kOhm sense resistor and a
// 3.3 V/12-bit ADC: 5.73 mA/count. Calibrate each assembled channel under load.
constexpr uint32_t CURRENT_MA_PER_ADC_COUNT_NUM = 57;
constexpr uint32_t CURRENT_MA_PER_ADC_COUNT_DEN = 10;

}  // namespace hw

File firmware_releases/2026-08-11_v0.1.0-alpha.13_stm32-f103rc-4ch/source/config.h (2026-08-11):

#pragma once

#include <Arduino.h>

namespace hw {

constexpr char FW_VERSION[] = "0.1.0-alpha.13-4ch-f103rc";
constexpr uint32_t FW_BUILD = 13;

constexpr uint8_t ACTUATOR_COUNT = 4;
constexpr uint8_t PHYSICAL_SLAVE_COUNT = 0;
constexpr uint8_t REQUIRED_LOGICAL_SLAVE_COUNT = 1;
constexpr uint8_t LOGICAL_SLAVE_MASK = 0x01;

constexpr PinName CURRENT_PINS[ACTUATOR_COUNT] = {PA_0, PA_1, PA_2, PA_3};
constexpr PinName PWM_PINS[ACTUATOR_COUNT] = {PA_8, PA_9, PA_10, PA_11};
constexpr PinName INA_PINS[ACTUATOR_COUNT] = {PB_0, PB_10, PB_12, PB_14};
constexpr PinName INB_PINS[ACTUATOR_COUNT] = {PB_1, PB_11, PB_13, PB_15};
constexpr PinName DIAG_PINS[ACTUATOR_COUNT] = {PC_6, PC_7, PC_8, PC_9};

constexpr PinName REED_PINS[3] = {PC_0, PC_1, PC_2};
constexpr PinName CAP_CS = PA_4;
constexpr PinName CAP_IRQ = PC_5;
constexpr PinName CAP_RESET = PC_10;
constexpr PinName CABINET_EEPROM_CS = PC_4;
constexpr PinName POWER_GOOD = PC_3;

// bxCAN is remapped from PA11/PA12 to PB8/PB9. PA11 remains TIM1_CH4.
constexpr PinName CAN_RX = PB_8;
constexpr PinName CAN_TX = PB_9;

constexpr uint32_t CAN_BITRATE = 500000;
constexpr uint32_t PWM_FREQUENCY_HZ = 20000;
constexpr uint16_t PWM_MAX = 1000;

constexpr uint32_t CONTROL_PERIOD_MS = 5;
constexpr uint32_t SENSOR_PERIOD_MS = 10;
constexpr uint32_t STATUS_PERIOD_MOVING_MS = 100;
constexpr uint32_t STATUS_PERIOD_IDLE_MS = 1000;
constexpr uint32_t HEARTBEAT_TIMEOUT_MS = 300;
constexpr uint32_t SLAVE_TIMEOUT_MS = 400;
constexpr uint32_t COMMAND_ARM_WINDOW_MS = 1000;
constexpr uint32_t DIRECTION_DEADTIME_MS = 30;
constexpr uint32_t OVERCURRENT_CONFIRM_MS = 60;
constexpr uint32_t NO_CURRENT_STARTUP_MS = 700;
constexpr uint32_t ENDSTOP_CONFIRM_MS = 250;
constexpr uint32_t DEFAULT_MAX_TRAVEL_MS = 45000;
constexpr uint32_t DEFAULT_MIN_TRAVEL_MS = 1500;
constexpr uint16_t DEFAULT_MAX_CURRENT_MA = 5000;
constexpr uint16_t DEFAULT_ZERO_CURRENT_MA = 100;
constexpr uint16_t DEFAULT_PWM_PERMILLE = 1000;
constexpr uint16_t MIN_CALIBRATION_PWM_PERMILLE = 600;
constexpr uint16_t LOW_SUPPLY_MV = 9500;

// Starting value for K0=7110, 1 kohm CS load and a 3.3 V/12-bit ADC.
// The 10 kohm ADC resistor is series protection, not a voltage divider.
constexpr uint32_t CURRENT_MA_PER_ADC_COUNT_NUM = 57;
constexpr uint32_t CURRENT_MA_PER_ADC_COUNT_DEN = 10;

}  // namespace hw

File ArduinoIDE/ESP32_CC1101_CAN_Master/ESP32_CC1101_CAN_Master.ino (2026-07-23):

#include <Arduino.h>
#include <ELECHOUSE_CC1101_SRC_DRV.h>
#include <ESPmDNS.h>
#include <Preferences.h>
#include <WebServer.h>
#include <WiFi.h>
#include <driver/twai.h>
#include <WindowBusProtocol.h>

#include "WebUi.h"

using namespace windowbus;

namespace {

constexpr char FW_VERSION[] = "0.1.0-alpha.11";
constexpr uint8_t FW_BUILD = 11;

constexpr int PIN_RF_SCK = 12;
constexpr int PIN_RF_MISO = 13;
constexpr int PIN_RF_MOSI = 11;
constexpr int PIN_RF_CS = 10;
constexpr int PIN_RF_GDO0 = 4;
constexpr int PIN_RF_GDO2 = 5;
constexpr int PIN_LEARN_BUTTON = 9;
constexpr int PIN_CAN_RX = 38;
constexpr int PIN_CAN_TX = 39;

constexpr char WEB_USER[] = "admin";
constexpr char WEB_PASSWORD[] = "admin12345";
constexpr char SETUP_AP_PASSWORD[] = "12345678";
constexpr uint32_t WIFI_CONNECT_TIMEOUT_MS = 15000;
constexpr uint32_t CAN_HEARTBEAT_MS = 100;
constexpr uint32_t OBJECT_OFFLINE_MS = 3000;
constexpr uint32_t COMMAND_MAX_MS = 60000;
constexpr uint32_t SLIDE_SEQUENCE_TIMEOUT_MS = 180000;
constexpr uint32_t SLIDE_MOVING_STATUS_TIMEOUT_MS = 500;
constexpr uint32_t SLIDE_IDLE_STATUS_TIMEOUT_MS = 1500;
constexpr uint16_t DEFAULT_SLIDE_DELAY_MS = 300;
constexpr uint8_t EVENT_COUNT = 48;
constexpr uint8_t REMOTE_COUNT = 36;
constexpr uint8_t DISCOVERY_COUNT = 24;
constexpr uint8_t NAME_LENGTH = 32;
constexpr uint32_t PROVISION_TIMEOUT_MS = 3000;
constexpr uint32_t CARRIER_BACKUP_MAGIC = 0x314B4243u;  // CBK1
constexpr uint8_t CARRIER_BACKUP_VERSION = 1;
constexpr uint32_t SYSTEM_BACKUP_MAGIC = 0x314B4257u;  // WBK1
constexpr uint16_t SYSTEM_BACKUP_VERSION = 2;

constexpr float RF_FREQUENCY_MHZ = 433.92f;
constexpr float RF_DATA_RATE_KBPS = 19.2f;
constexpr uint32_t RF_IDLE_FRAME_US = 18000;
constexpr uint32_t RF_DEBOUNCE_MS = 250;
constexpr size_t RF_MAX_PULSES = 180;
constexpr uint32_t RF_SHORT_MIN_US = 180;
constexpr uint32_t RF_SHORT_MAX_US = 560;
constexpr uint32_t RF_LONG_MIN_US = 650;
constexpr uint32_t RF_LONG_MAX_US = 1300;
constexpr uint32_t RF_SYNC_MIN_US = 5000;
constexpr uint32_t RF_SYNC_MAX_US = 14000;
constexpr uint8_t RF_EXPECTED_BITS = 24;
constexpr uint32_t LEARN_TIMEOUT_MS = 30000;
constexpr uint32_t LEARN_BUTTON_LONG_MS = 5000;

#pragma pack(push, 1)
struct ObjectConfig {
  uint8_t enabled;
  uint8_t id;
  uint8_t cabinetId;
  uint8_t type;
  uint8_t actuatorCount;
  uint8_t slaveCount;
  char name[NAME_LENGTH];
  uint8_t capEnabledMask;
};

struct RemoteRecord {
  uint32_t code;
  uint64_t targetMask;
  uint8_t command;
  uint8_t enabled;
  char name[NAME_LENGTH];
};

struct CarrierBackupRecord {
  uint32_t magic;
  uint8_t version;
  uint8_t valid;
  uint8_t cabinetId;
  uint8_t objectType;
  uint8_t actuatorCount;
  uint8_t slaveCount;
  uint8_t reedPolarityMask;
  uint8_t capEnabledMask;
  uint32_t sourceUidHash;
  uint16_t configRevision;
  char name[NAME_LENGTH];
  uint16_t crc;
};

struct SlideConfig {
  uint8_t enabled;
  uint8_t auxCabinetId;
  uint16_t openDelayMs;
  uint16_t closeDelayMs;
};

struct SystemBackupPayloadV1 {
  char wifiSsid[33];
  char wifiPassword[65];
  char systemName[NAME_LENGTH];
  uint8_t objectCount;
  uint8_t remoteCount;
  ObjectConfig objects[MAX_CABINETS];
  uint8_t reedPolarityMasks[MAX_CABINETS];
  RemoteRecord remotes[REMOTE_COUNT];
  CarrierBackupRecord carrierBackups[MAX_CABINETS];
};

struct SystemBackupPayload {
  char wifiSsid[33];
  char wifiPassword[65];
  char systemName[NAME_LENGTH];
  uint8_t objectCount;
  uint8_t remoteCount;
  ObjectConfig objects[MAX_CABINETS];
  uint8_t reedPolarityMasks[MAX_CABINETS];
  RemoteRecord remotes[REMOTE_COUNT];
  CarrierBackupRecord carrierBackups[MAX_CABINETS];
  SlideConfig slideConfigs[MAX_CABINETS];
};

struct SystemBackupFileV1 {
  uint32_t magic;
  uint16_t version;
  uint16_t payloadSize;
  uint32_t crc32;
  SystemBackupPayloadV1 payload;
};

struct SystemBackupFile {
  uint32_t magic;
  uint16_t version;
  uint16_t payloadSize;
  uint32_t crc32;
  SystemBackupPayload payload;
};
#pragma pack(pop)

static_assert(offsetof(SystemBackupPayload, slideConfigs) == sizeof(SystemBackupPayloadV1),
              "V2 backup must preserve the complete V1 payload prefix");

struct ActuatorRuntime {
  uint16_t currentMa = 0;
  uint8_t pwmRaw = 0;
  uint8_t flags = 0;
  bool online = false;
};

struct ObjectRuntime {
  bool online = false;
  uint8_t state = static_cast<uint8_t>(RunState::Boot);
  uint8_t target = static_cast<uint8_t>(Command::None);
  uint8_t position = static_cast<uint8_t>(Position::Unknown);
  uint8_t fault = static_cast<uint8_t>(Fault::None);
  uint8_t faultActuator = 0;
  uint8_t slaveMask = 0;
  uint8_t reedMask = 0;
  uint8_t capMask = 0;
  uint8_t sensorFlags = 0;
  uint8_t bootId = 0;
  uint8_t lastFault = 0;
  uint8_t commandSequence = 0;
  Command heartbeatCommand = Command::None;
  Command pendingCalibration = Command::None;
  bool calibrationSawMotion = false;
  uint32_t lastSeen = 0;
  uint32_t nextHeartbeat = 0;
  uint32_t commandStarted = 0;
  ActuatorRuntime actuators[MAX_ACTUATORS_PER_CABINET];
};

enum class SlidePhase : uint8_t {
  Idle = 0,
  WaitPrimaryOpen = 1,
  OpenDelay = 2,
  WaitSlideOpen = 3,
  WaitSlideClosed = 4,
  CloseDelay = 5,
  WaitPrimaryClosed = 6,
};

struct SlideSequenceRuntime {
  SlidePhase phase = SlidePhase::Idle;
  uint8_t auxiliaryIndex = 0xFF;
  uint32_t startedAt = 0;
  uint32_t delayUntil = 0;
};

struct EventRecord {
  uint32_t timestamp;
  uint8_t objectId;
  uint8_t code;
  uint8_t actuator;
  char text[48];
};

struct DiscoveryRecord {
  uint32_t uidHash = 0;
  uint8_t configured = 0;
  uint8_t cabinetId = 0xFF;
  uint8_t role = 0;
  uint8_t firmware = 0;
  uint32_t lastSeen = 0;
};

enum class ProvisionTransactionState : uint8_t {
  Idle = 0,
  Pending = 1,
  Success = 2,
  Failed = 3,
  TimedOut = 4,
};
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

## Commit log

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2026-06-21 Prevent web UI request stalls
    [ESP32_CC1101_RS485_Master.ino]
2026-06-21 Stabilize mobile control layout
    [ESP32_CC1101_RS485_Master.ino]
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2026-07-14 Fix mobile web layout and add browser test fixture
    [ESP32_CC1101_CAN_Master.ino]
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2026-07-15 Correct CAN transceiver count in BOM
2026-07-15 Correct BOM counts and allow window without CAP1188
    [STM32_Universal_Actuator_Node.ino]
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2026-07-15 Start KiCad source for DOOR-8CH
    [DOOR-8CH.kicad_pcb]
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2026-07-15 Place VNH channels and terminals on DOOR-8CH
    [DOOR-8CH.kicad_pcb]
2026-07-15 Add control-module sockets to DOOR-8CH placement
    [DOOR-8CH.kicad_pcb]
2026-07-15 Correct DOOR-8CH placement from module photos
    [DOOR-8CH.kicad_pcb]
2026-07-15 Add CAP1188 configuration and onboard power layout
    [DOOR-8CH.kicad_pcb]
2026-07-15 Add DOOR-8CH VNH electrical placement
    [DOOR-8CH.kicad_pcb]
2026-07-15 Add DOOR-8CH low-voltage nets
    [DOOR-8CH.kicad_pcb]
2026-07-15 Add carrier EEPROM support
    [DOOR-8CH.kicad_pcb]
2026-07-15 Move CAN entry next to CAN2
    [DOOR-8CH.kicad_pcb]
2026-07-15 Compact CAN entry at board edge
    [DOOR-8CH.kicad_pcb]
2026-07-16 Route protected CAN entry
    [DOOR-8CH.kicad_pcb]
2026-07-16 Compact VNH power stage placement
    [DOOR-8CH.kicad_pcb]
2026-07-16 Route independent VNH supply feeds
    [DOOR-8CH.kicad_pcb]
2026-07-16 Add internal ground planes
    [DOOR-8CH.kicad_pcb]
2026-07-16 Route protected CAN trunk to both transceivers
    [DOOR-8CH.kicad_pcb]
2026-07-16 Route STM32 CAN1 control signals
    [DOOR-8CH.kicad_pcb]
2026-07-16 Route ESP32 CAN2 control signals
    [DOOR-8CH.kicad_pcb]
2026-07-16 Route protected logic power distribution
    [DOOR-8CH.kicad_pcb]
2026-07-16 Connect CAP1188 to logic 5V rail
    [DOOR-8CH.kicad_pcb]
2026-07-16 Power CAP1188 from 3V3 rail
    [DOOR-8CH.kicad_pcb]
2026-07-16 Revert "Power CAP1188 from 3V3 rail"
    This reverts commit aa226b984f944179432c3d01fdd3c0ed828e7055.
    [DOOR-8CH.kicad_pcb]
2026-07-16 Distribute 3V3 to CAN RF and carrier EEPROM
    [DOOR-8CH.kicad_pcb]
2026-07-16 Complete EEPROM 3V3 pullup network
    [DOOR-8CH.kicad_pcb]
2026-07-16 Route EEPROM write protect and hold controls
    [DOOR-8CH.kicad_pcb]
2026-07-16 Route channel 1 VNH control inputs
    [DOOR-8CH.kicad_pcb]
2026-07-16 Route channel 1 current filter
    [DOOR-8CH.kicad_pcb]
2026-07-16 Route channel 2 VNH control inputs
    [DOOR-8CH.kicad_pcb]
2026-07-16 Route channel 2 current filter
    [DOOR-8CH.kicad_pcb]
2026-07-16 Route channel 1 current-sense enable strap
    [DOOR-8CH.kicad_pcb]
2026-07-16 Route channel 2 current-sense enable strap
    [DOOR-8CH.kicad_pcb]
2026-07-16 Route local 3V3 scaler branches for channels 1 and 2
    [DOOR-8CH.kicad_pcb]
2026-07-16 Route channels 1 and 2 current sense paths to STM32
    [DOOR-8CH.kicad_pcb]
2026-07-16 Route channel 3 controls and current measurement
    [DOOR-8CH.kicad_pcb]
2026-07-16 Route channel 4 controls and local current filter
    [DOOR-8CH.kicad_pcb]
2026-07-16 Route channels 5-8 VNH control inputs
    [DOOR-8CH.kicad_pcb]
2026-07-16 Route channels 5-8 current filters
    [DOOR-8CH.kicad_pcb]
2026-07-16 Route channel 4 current ADC to STM32
    [DOOR-8CH.kicad_pcb]
2026-07-16 Route channels 5-8 current ADC inputs
    [DOOR-8CH.kicad_pcb]
2026-07-16 Route channels 3-8 local 3V3 links
    [DOOR-8CH.kicad_pcb]
2026-07-16 Route channels 3-8 raw current dividers
    [DOOR-8CH.kicad_pcb]
2026-07-16 Route channel 3 4 6 7 current sense disable
    [DOOR-8CH.kicad_pcb]
2026-07-16 Route channel 5 current sense disable
    [DOOR-8CH.kicad_pcb]
2026-07-16 Route channel 8 CS disable and clear supply escape
    [DOOR-8CH.kicad_pcb]
2026-07-16 Route S4 local 3V3 distribution
    [DOOR-8CH.kicad_pcb]
2026-07-16 Route S3 local 3V3 distribution
    [DOOR-8CH.kicad_pcb]
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2026-07-16 hardware: autoroute low-current door signals
    [DOOR-8CH-power-v1.36.dsn]
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2026-07-16 Add DOOR-8CH principle schematics and finish sensor reroute
    [DOOR-8CH-cap1188.kicad_sch, DOOR-8CH-channel-1.kicad_sch, DOOR-8CH-channel-2.kicad_sch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]
2026-07-16 Add DOOR-8CH power-fail hold-up and persistent journal
    [DOOR-8CH-cap1188.kicad_sch, DOOR-8CH-channel-1.kicad_sch, DOOR-8CH-channel-2.kicad_sch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]
2026-07-18 Add routed WINDOW-4CH carrier and STM32 5A release
    [WINDOW-4CH-BOM.csv, WINDOW-4CH-cap1188.kicad_sch, WINDOW-4CH-channel-1.kicad_sch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]
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2026-07-21 Correct ESP32 socket spacing and release PCB v1.47
    [DOOR-8CH-B_Cu.gbr, DOOR-8CH-B_Mask.gbr, DOOR-8CH-Edge_Cuts.gbr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]
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2026-07-23 Add compact universal two-channel actuator board
    [UNIVERSAL-2CH-BOM.csv, UNIVERSAL-2CH-cap1188.kicad_sch, UNIVERSAL-2CH-channel-1.kicad_sch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]
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2026-07-23 Complete compact 2-channel PCB routing
    [UNIVERSAL-2CH-cap1188.kicad_sch, UNIVERSAL-2CH-channel-1.kicad_sch, UNIVERSAL-2CH-channel-2.kicad_sch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]
2026-07-23 Add UNIVERSAL-2CH JLCPCB SMD release
    [UNIVERSAL-2CH-B_Cu.gbr, UNIVERSAL-2CH-Edge_Cuts.gbr, UNIVERSAL-2CH-F_Cu.gbr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]
2026-07-25 Add DOOR-8CH JLCPCB release v1.48
    [DOOR-8CH-B_Cu.gbr, DOOR-8CH-B_Mask.gbr, DOOR-8CH-Edge_Cuts.gbr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]
2026-08-04 Add UNIVERSAL-2CH F103 mask-fixed release v1.1
    [UNIVERSAL-2CH-F103-IC-B_Cu.gbr, UNIVERSAL-2CH-F103-IC-B_Mask.gbr, UNIVERSAL-2CH-F103-IC-Edge_Cuts.gbr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]
2026-08-05 Verify 2CH JLCPCB component orientations
    [UNIVERSAL-2CH-F103-IC-B_Cu.gbr, UNIVERSAL-2CH-F103-IC-B_Mask.gbr, UNIVERSAL-2CH-F103-IC-Edge_Cuts.gbr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]
2026-08-05 hardware: release 2ch board v1.5 with stocked CAN choke
    [UNIVERSAL-2CH-F103-IC-B_Cu.gbr, UNIVERSAL-2CH-F103-IC-B_Mask.gbr, UNIVERSAL-2CH-F103-IC-Edge_Cuts.gbr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]
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2026-08-11 Fix universal 4ch power routing
    [UNIVERSAL-4CH-F103RC-IC.kicad_pcb]
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2026-08-11 Reinforce four-channel motor layer transitions
    [UNIVERSAL-4CH-F103RC-IC.kicad_pcb]
2026-08-11 Expand channel 1 and 2 power via banks
    [UNIVERSAL-4CH-F103RC-IC.kicad_pcb]
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2026-08-11 Add JLCPCB releases for 2CH and 4CH controllers
    [UNIVERSAL-2CH-F103-IC-B_Cu.gbr, UNIVERSAL-2CH-F103-IC-B_Mask.gbr, UNIVERSAL-2CH-F103-IC-B_Paste.gbr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]
2026-08-12 Fix 2-channel DC-DC footprint for 15x9 mm pins
    [UNIVERSAL-2CH-F103-IC.kicad_pcb]
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2026-09-05 Fix two-channel safety checks and protected supervisor supply
    [UNIVERSAL-2CH-F103-IC.kicad_pcb]
2026-09-06 Clean two-channel DRC and publish v1.7 fabrication files
    [UNIVERSAL-2CH-F103-IC-B_Cu.gbr, UNIVERSAL-2CH-F103-IC-B_Mask.gbr, UNIVERSAL-2CH-F103-IC-B_Paste.gbr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]
